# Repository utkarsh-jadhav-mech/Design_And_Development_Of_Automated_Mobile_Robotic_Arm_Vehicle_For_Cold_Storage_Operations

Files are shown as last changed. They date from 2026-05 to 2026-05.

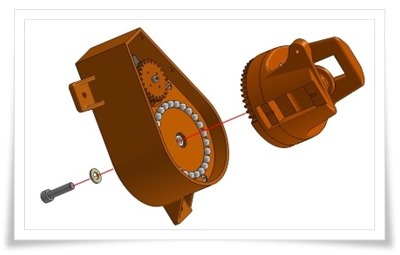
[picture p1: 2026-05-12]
Image/Assembly_Steps/Arm_Assembly_Steps/Software_Assembly/IMG-20241116-WA0014.jpg

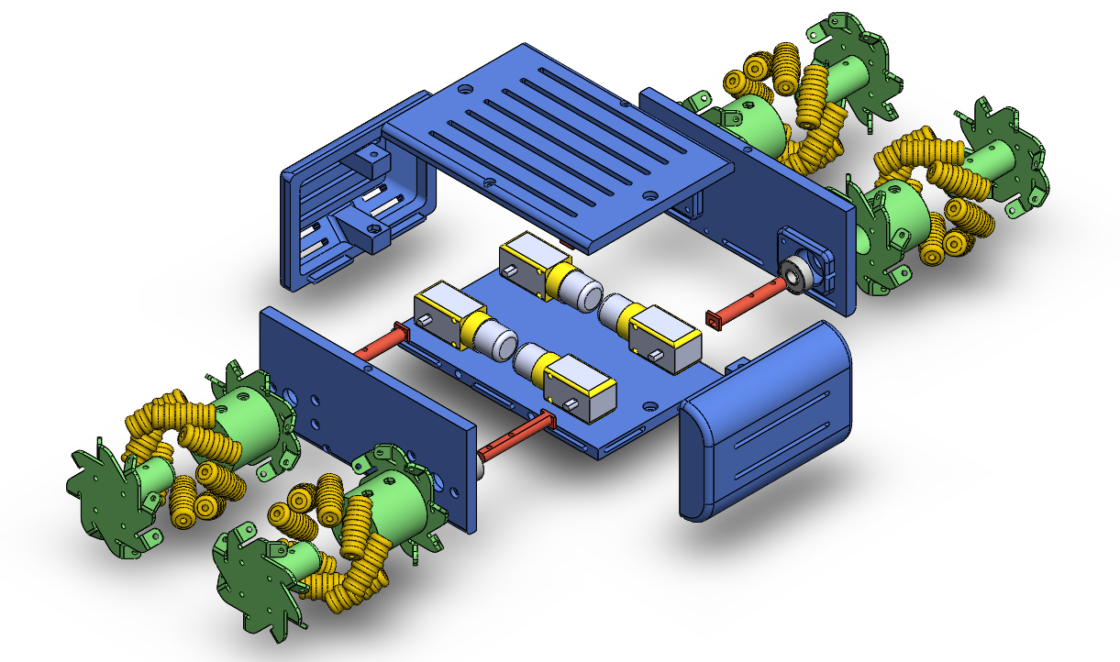
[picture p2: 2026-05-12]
Image/Assembly_Steps/Vehicle_Assembly_Steps/Software_Assembly/Exp_BLT_Pers.png

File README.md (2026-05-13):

# Design And Development of Automated Mobile Robotic Arm Vehicle for Cold Storage Operations

## Final Year Mechanical Engineering Project

An automated mobile robotic arm designed for cold storage operations to reduce manual labor, improve safety, and increase operational efficiency in low-temperature environments.

<br>
Final_Demontration
<br>

## Table of Contents

1. [Project Summary](#project-summary)  
2. [Project Overview](#project-overview)  
3. [Project Focus](#project-focus)  
4. [Project Objectives](#project-objectives)  
5. [Certificate of Journal and Conference](#certificate-of-journal-and-conference)
6. [Certificate Images](#certificate-images)
7. [Hardware Components](#hardware-components)
8.  [Software Used](#software-used)  
9. [Materials Used](#materials-used)  
10. [Engineering Calculations](#engineering-calculations)
11. [CAD Design](#cad-design)
12. [Working Principle](#working-principle)
13. [Project Development Process](#project-development-process)
14. [Results](#results)
15. [Applications](#applications)
16. [Skills Developed](#skills-developed)
17. [Contributing](#contributing)
18. [Future Improvements](#future-improvements)
19. [Author](#author)
20. [Final Note](#final-note)

## Project Summary

The **Automated Mobile Robotic Arm Vehicle for Cold Storage Operations** is a final year mechanical engineering project focused on automating material handling tasks in cold storage environments. The system combines a mobile robotic platform with a robotic arm capable of pick-and-place operations using Arduino-based control and Bluetooth communication.

The project utilizes components such as MG995 servo motors, Arduino Uno, HC-05 Bluetooth module, L298N motor driver, and 3D printed mechanical parts designed in SolidWorks. The robotic system is developed to reduce manual labor, improve operational safety, and increase efficiency in low-temperature industrial environments.

This project integrates mechanical design, embedded systems, robotics, CAD modeling, and automation technologies into a practical industrial application.

## Project Overview

The **Automated Mobile Robotic Arm Vehicle for Cold Storage Operations** is a final year mechanical engineering project designed to automate material handling tasks in cold storage environments. The system combines a mobile robotic platform with a robotic arm capable of performing pick-and-place operations through wireless Bluetooth control.

The project uses components such as Arduino Uno, MG995 servo motors, HC-05 Bluetooth module, L298N motor driver, and 3D printed mechanical parts. The main objective is to reduce manual labor, improve worker safety, and increase operational efficiency in low-temperature storage facilities through robotic automation.

## Project Focus

The main focus of this project is:
- Automation in cold storage environments
- Mobile robotics
- Robotic arm manipulation
- Wireless robotic control
- Embedded systems integration
- Mechanical system design

# Project Objectives

- Reduce manual labor in cold storage
- Improve operational safety
- Develop an automated handling system
- Enable wireless robotic control
- Design a low-cost automation solution
- Improve material transportation efficiency

## Certificate of Journal and Conference

### Journal Publication Certificate

This project research work was successfully published/presented in a reputed engineering journal based on robotics, automation, and cold storage applications.

#### Research Area
- Robotics and Automation
- Cold Storage Automation
- Embedded Systems
- Mobile Robotic Arm
- Industrial Automation

#### Published Research Title
**Development of Automated Mobile Robotic Arm Vehicle for Cold Storage Operations**

#### Journal Details
| Details | Information |
|---|---|
| Journal Name | IRJMETS |
| Paper ID |IRJMETS70400360229 |
| Volume | 07 |
| Issue | 04 |
| Publication Year | 2026 |
| ISSN Number | 2582-5208 |
| DOI | https://www.doi.org/10.56726/IRJMETS75091 |

### Conference Presentation Certificate

The project was also presented at a technical conference/seminar related to engineering innovation and automation technologies.

#### Conference Presentation Title
**Development of Automated Mobile Robotic Arm Vehicle for Cold Storage Operations**

#### Conference Details

| Details | Information |
|---|---|
| Conference Name | International Conference on Recent Advances in Engineering and Sciences – 2025 (ICRAES-2K25) |
| Organized By | Bharati Vidyapeeth’s College of Engineering, Lavale, Pune |
| Presentation Type | Technical Paper Presentation |
| Conference Year | 2025 |
| Location | Pune, India |

## Certificate Images

### Journal Certificate
<BR>
Journal_Certificate
<BR>

### Conference Certificate
<BR>
Conference_Certificate
<BR>

## Hardware Components

| Sr No | Component | Specification |
|---|---|---|
| 1 | Servo Motor | MG995 High Torque Servo |
| 2 | Micro Servo | SG90 |
| 3 | Controller | Arduino Uno |
| 4 | Servo Controller | USB Bluetooth 18 Servo Controller |
| 5 | Motor Driver | L298N |
| 6 | Bluetooth Module | HC-05 |
| 7 | Battery | Samsung 7.4V 2600mAh Li-Ion |
| 8 | Stepper Motor | NEMA Stepper Motor |
| 9 | Bearings | 606ZZ / 608ZZ |
| 10 | Wheels | Robotic Wheels |

## Software Used

- Arduino IDE
- SolidWorks
- Tinkercad
- RoboKits Servo Controller Software
- FlashPrint

## Materials Used

| Material | Purpose |
|---|---|
| PLA Filament | 3D Printed Parts |
| Aluminum Frame | Structural Support |
| Rubber Wheels | Mobile Movement |
| Bearings 606ZZ / 608ZZ | Smooth Rotation |
| Servo Mounts | Joint Assembly |

## Engineering Calculations

### Payload Capacity

- Expected Payload = 100 g
- Safety Factor = 1.5
- Safe Payload = 150 g

### Torque Calculation

Formula:

```math
T = F × r
```

Calculated Torque:
- Force = 1.962 N
- Torque = 0.981 N·m
- Equivalent Torque ≈ 10 kg/cm

### Power Consumption

```math
P = V × I
```

- Voltage = 6V
- Current = 2.5A
- Total Power = 45W

### Battery Backup

- Battery Energy = 19.24 Wh
- Estimated Backup = 26 Minutes

## CAD Design

The robotic arm and chassis were designed using **SolidWorks**.

Designed Components:
- Robotic arm links
- Gripper mechanism
- Servo mounts
- Mobile chassis
- Wheel assembly

The CAD models were exported as STL files for 3D printing.

## Working Principle

1. User sends command via Bluetooth.
2. HC-05 module receives data.
3. Arduino processes the command.
4. Servo controller drives robotic arm motors.
5. L298N controls wheel movement.
6. Robotic arm performs handling operation.

## Project Development Process

### Step 1 — Requirement Analysis
- Studied cold storage operational problems
- Identified automation requirements

### Step 2 — CAD Modeling
- Designed robotic arm in SolidWorks
- Created assembly and motion design

### Step 3 — 3D Printing
- Converted STL files
- Printed mechanical components

### Step 4 — Electronics Integration
- Connected Arduino and motor drivers
- Installed Bluetooth communication system

### Step 5 — Programming
- Developed Arduino control code
- Implemented motor movement logic

### Step 6 — Testing
- Tested robotic arm movement
- Checked wireless communication
- Performed cold condition trials

## Results

- Successful robotic movement
- Stable Bluetooth communication
- Reliable pick-and-place operation
- Accurate servo control
- Efficient mobility in testing conditions

## Applications

- Cold storage warehouses
- Industrial automation systems
- Smart logistics and material handling
- Food and pharmaceutical storage facilities
- Hazardous environment operations

## Skills Developed

- SolidWorks CAD Modeling
- 3D Printing
- Basic Arduino Programming
- Embedded Systems
- Robotics Integration
- Mechanical Assembly
- Engineering Design

## Contributing

Contributions, suggestions, and improvements related to CAD modeling, simulation, robotic arm control, and automated mobile robotic system design for cold storage applications are welcome. Feel free to fork the repository and submit pull requests for enhancements.

## Future Improvements

- AI-based navigation
- Computer vision integration
- IoT monitoring system
- Implementation of autonomous navigation using SLAM
- AI-based object detection for intelligent picking
- IoT-based monitoring system
- Fully automated charging station integration
- Multi-robot coordination for warehouse automation
- Obstacle avoidance system

## Author

**Utkarsh Jadhav**  
Mechanical Engineering Student | CAD Designer | Robotics Enthusiast  

- GitHub: https://github.com/utkarsh-jadhav-mech
- LinkedIn: https://www.linkedin.com/in/utkarsh-jadhav-mech

### Team Members
- Girish Patil
- Subodh Bhosale
- Sunil Dhargude
- Omkar Pore

### Guided By
**Prof. S. H. Kumbhar** 

## Final Note

This project represents an integration of mechanical design, electronics, and automation for cold storage applications. It demonstrates the practical implementation of a mobile robotic arm system aimed at improving efficiency, safety, and productivity in industrial environments.

Continuous improvements and innovative ideas are always encouraged to enhance the performance and real-world applicability of this system.

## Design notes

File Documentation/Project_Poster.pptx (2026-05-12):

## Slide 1

“Development of Automated Mobile Robotic Arm for Cold Storage Operations”

Subodh Bhosale (244418 ) Girish Patil (244425) Utkarsh Jadhav (244426)
Omkar Pore (244460) Sunil Dhargude (244464 )
Under Guidance of :- Prof. S. H. Kumbhar
Academic Year 2024-25
Department of Mechanical Engineering, VPKBIET Baramati

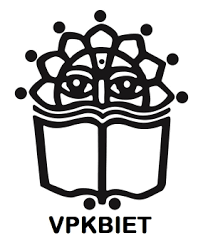
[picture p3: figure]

Abstract

The development of an automatic mobile robotic arm for cold storage operations is aimed at enhancing efficiency, accuracy and security in the environment, where temperature-sensitive items are handled. This robotic system is designed to autonomally navigate cold storage features, pick, sort and store items and operate tasks such as storing and operating in tight temperature conditions. This innovation is particularly important for industries such as food and pharmaceuticals, where it is important to maintain the integrity of temperature
sensitive products. Robotic arm dynamics allow it to make it favourable to various cold storage configurations, while its exact control mechanisms ensure safe handling of delicate objects. The system not only strengthens operations, but also improves security by reducing human risk for extremely cold environment, which leads to better overall productivity and cost savings.

Objectives

- Robotic Arm Design & Development
- Cold-Resistant Materials & Components
- Enhanced Speed & Precision
- Worker Safety & Injury Prevention
- System Testing & Optimization
- AI & Automation Integration

Results

For the development of an automated mobile robotic arm in cold storage operations:
• The payload capacity should be designed for at least 0.26 kg with an overload protection factor.
• The joint torque requirement is 10.00 kg.cm (98.1 N.cm) for smooth operation.
• The motor power requirement is 2.05 W, ensuring energy-efficient operation.
These calculations provide a fundamental basis for selecting appropriate actuators, ensuring reliability in cold storage environments. Further refinements should consider frictional losses, joint dynamics, and environmental
adaptations.

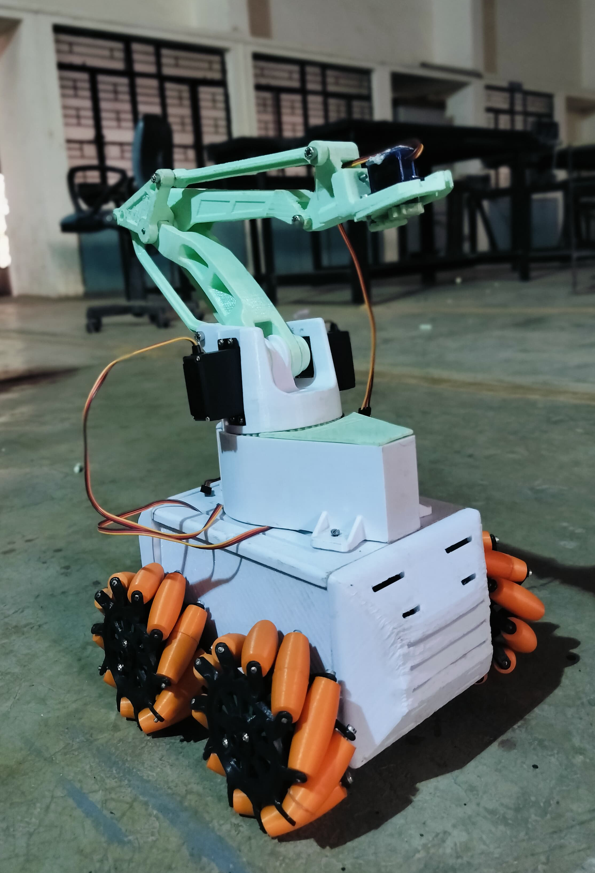
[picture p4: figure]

Methodology

- Design of Robotic Arm
- Motor and Servo Selection for Cold Storage
- Battery and Power Management System
- Mobility and Navigation System
- Control System and Software Integration
- Testing and Evaluation Protocol

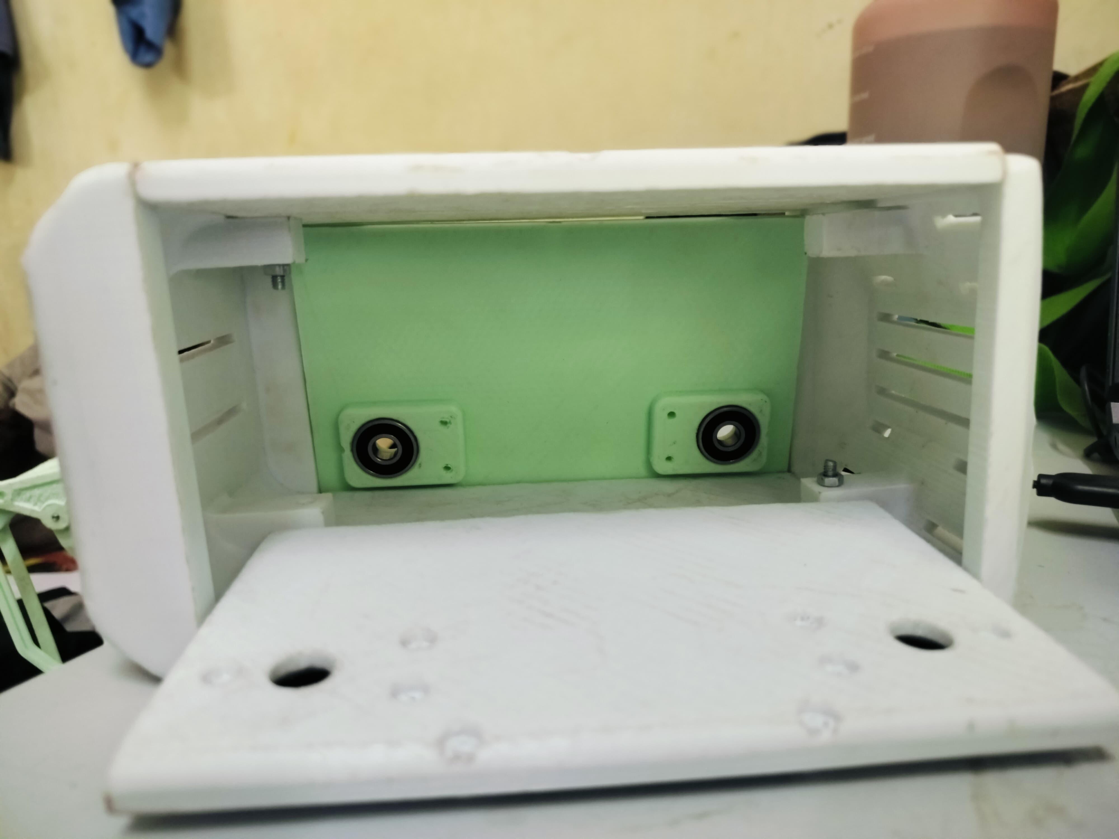
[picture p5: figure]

Fig.1 Automated Robotic Car Assembly Part

Fig.2 Robotic Aram Assembly Part

Introduction

Cold storage facilities play a crucial role in industries like food processing, pharmaceuticals, and biotechnology, where temperature-sensitive goods need to be stored and transported under controlled conditions. However, the extreme low temperatures in these environments create significant challenges for traditional manual handling and existing automation systems. Workers face health risks, and productivity is often slow and labor-intensive.
To address these challenges, automation in cold storage is increasingly becoming a necessity. Automated systems, such as robotic arms and mobile platforms, can enhance efficiency, reduce human exposure to cold, and improve safety. However,
most existing systems are not designed for the harsh conditions of cold storage, limiting their effectiveness.
This project focuses on the development of an “Automated Mobile Robotic Arm (AMRA)” for cold storage environments. The goal is to design a robotic arm capable of autonomously retrieving, placing, and transporting items with high precision in sub-zero temperatures. The robotic arm will be mounted on a mobile platform, allowing it to navigate aisles, avoid obstacles, and adapt to different layouts within the cold storage facility.
The aim is to improve operational efficiency, reduce labor costs, and enhance worker safety by minimizing human intervention. This system will also ensure the
careful handling of temperature-sensitive goods, thus improving the overall productivity and safety of cold storage operations. The following sections will detail
the design, development, and testing of the AMRA, focusing on its hardware, software, and integration into a cold storage environment..

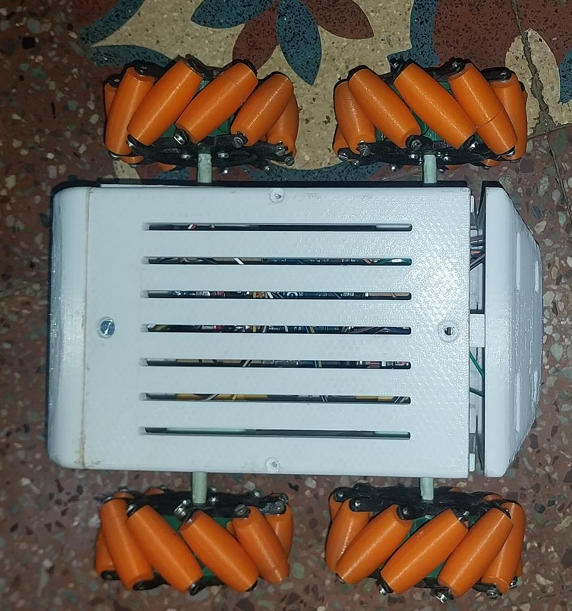
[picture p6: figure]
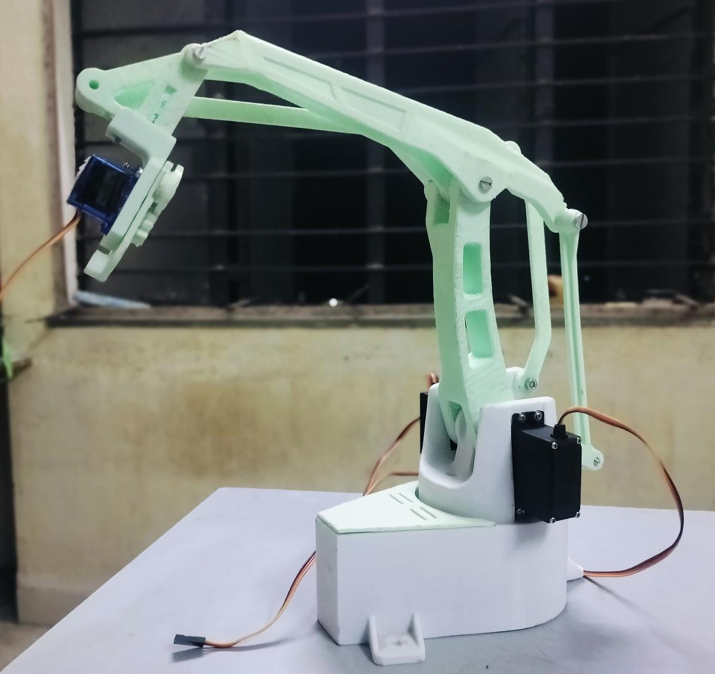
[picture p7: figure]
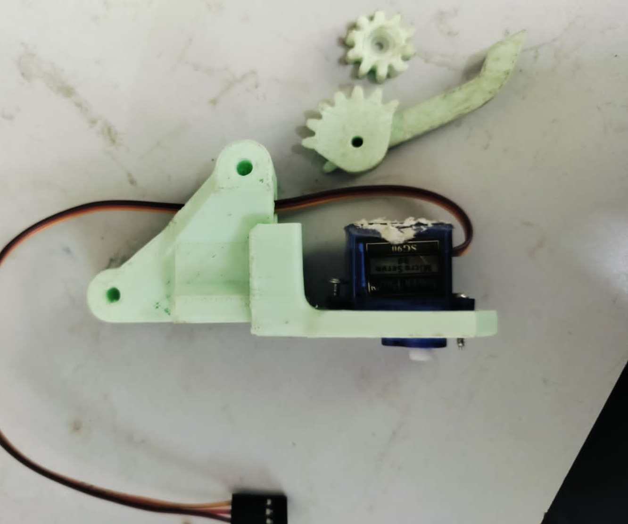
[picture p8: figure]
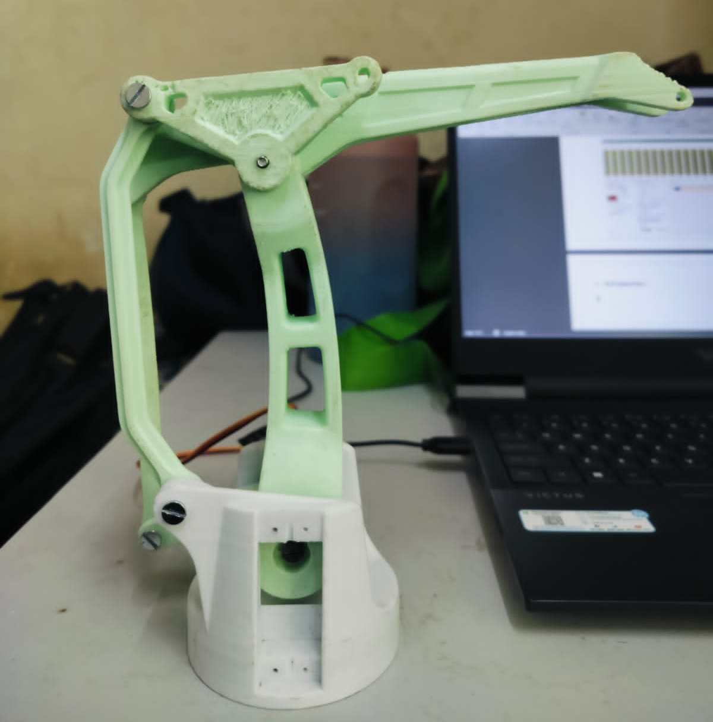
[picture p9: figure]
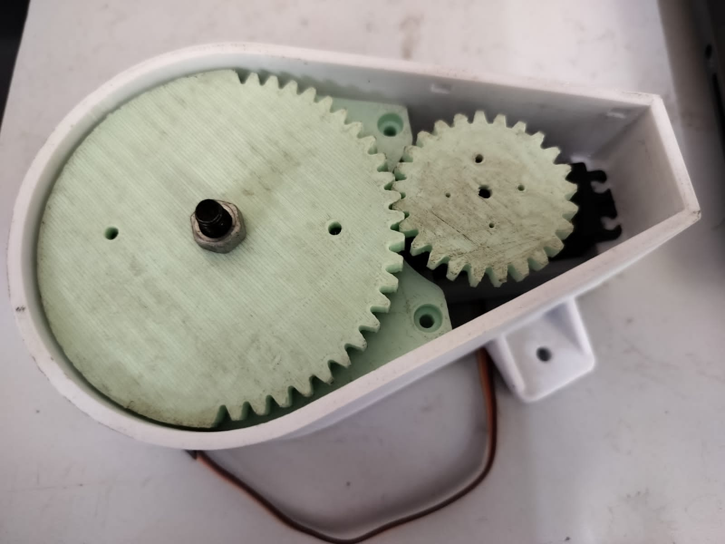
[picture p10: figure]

Conclusion

Integrating the EEZYBotArm MK2 with an omnidirectional mobile platform enhances efficiency in industrial settings like cold storage. This setup enables precise manipulation, flexible mobility, and seamless navigation. Future advancements may include AI automation, advanced sensors, and IoT connectivity for real-time optimization, boosting productivity and safety.

References

1.Smith, J. A., & Doe, R. (2022). Robotic Arms in Industrial Automation. Journal of Robotics, 15(4), 123-134.
2. Lee, C., & Wang, H. (2021). Advancements in Cold Storage Automation. International Conference on Robotics and Automation, 98-106.
3. Brown, T., & Green, R. (2020). Impact of Low Temperatures on Robotic Systems. Journal of Mechanical Design, 142(6), 654-670.
4. CESAREO CONTRERAS Autonomous Mobile Robot Makers Answer the Call During Holiday Rush.
5. Namita Sharma, Sadaf Anjum, Amrah Maryam, Savita Gautam (2024), Robotic Arm Car: A Mobile Solution For Automated Pick And Place Operations.

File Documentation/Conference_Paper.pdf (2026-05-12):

# Design and development of automated mobile robotic arm vehicle for cold storage operations

1

st Mr. Omkar Pore
dept.of Mechanical engineering VPKBIET, Baramati
Baramati,India
omkarpore03@gmail.com

4

th Mr. Subodh Bhosale
dept.of Mechanical Engineering VPKBIET, Baramati
Baramati, India
subodhbhosale0803@gmail.com

2

nd Mr. Girish Patil
dept.of Mechanical Engineering VPKBIET, Baramati
Baramati, India
girishpatil1705@gmail.com

5

th prof. Suraj Kumbhar
dept.of Mechanical Engineering VPKBIET, Baramati
Baramati, India
surajkumbhar6@gmail.com

3

rd Mr. Utkarsh Jadhav
dept.of Mechanical Engineering VPKBIET,Baramati
Baramati, India
utkarshjadhav994@gmail.com

Abstract— The development of an automatic mobile robotic arm for cold storage operations is aimed at enhancing efficiency, accuracy and security in the environment, where temperature-sensitive items are handled. This robotic system is designed to autonomally navigate cold storage features, pick, sort and store items and operate tasks such as storing and operating in tight temperature conditions. This innovation is particularly important for industries such as food and pharmaceuticals, where it is important to maintain the integrity of temperature-sensitive products. Robotic arm dynamics allow it to make it favourable to various cold storage configurations, while its exact control mechanisms ensure safe handling of delicate objects. The system not only strengthens operations, but also improves security by reducing human risk for extremely cold environment, which leads to better overall productivity and cost savings.

Keywords— Automatic mobile robotic arm, robotic system

I. INTRODUCTION
Cold storage warehouses play a crucial role in supply chains for perishable goods such as food, pharmaceuticals, and chemicals. However, extreme cold temperatures (as low as -30°C) make human labor inefficient, causing fatigue, reduced productivity, and health risks. Traditional robotic solutions are often fixed in place, limiting adaptability in dynamic storage environments.This research aims to develop a mobile robotic arm system capable of navigating cold storage environments, identifying goods, and performing automated retrieval and placement operations. The system is designed to work autonomously or via remote control, using AI-based object
recognition, | LiDAR-based | navigation, | and | real-time
environmental adaptation.

II. LITERATURE SURVEY

A. litarature review
- Cold Storage Challenges in Warehouse Automation. Cold storage environments present unique challenges for automation, primarily due to extreme temperatures affecting mechanical components, electronics, and human labor. Studies by Bakker et al. (2021) highlight that worker fatigue and health risks significantly impact operational efficiency in sub-zero environments. Traditional robotic systems struggle with condensation, low battery performance, and material brittleness at extremely low temperatures (Kim & Lee, 2020).
- Robotic Systems for Warehouse Automation
The application of robotics in warehouses has been widely explored, particularly through Automated Storage and

Retrieval Systems (AS/RS). Research by Zhong et al. (2019) emphasizes that AS/RS improves efficiency and reduces labor costs, but these systems are typically fixed, limiting adaptability in dynamic environments. Autonomous Mobile Robots (AMRs), such as those developed by Amazon Robotics and Fetch Robotics, have shown promise in general warehouse automation, but studies indicate they require modifications for cold storage, including insulation and specialized sensors (Gao et al., 2022).
- Mobile Robotic Arms in Logistics
Mobile robotic arms combine the benefits of mobility and precise object manipulation. Wurman et al. (2017) explored the use of robotic arms for logistics applications, noting improvements in order fulfillment speed. However, their effectiveness in cold storage has not been extensively studied. More recent advancements, such as those by Gupta et al. (2023), demonstrate AI-powered mobile robots performing autonomous retrieval and placement, but without adaptations for sub-zero conditions.
- | AI-Based | Object | Recognition | for | Cold
Environments

AI-based vision systems have been widely adopted in warehouse automation, with Convolutional Neural Networks (CNNs) and deep learning models proving effective in object detection and classification (Redmon & Farhadi, 2018). However, cold storage conditions introduce challenges such as frost accumulation, low lighting, and visual obstructions due to fogging (Chen et al., 2021). Solutions such as infrared imaging and sensor fusion have been proposed to enhance object recognition reliability in extreme conditions (Huang et al., 2022).

- LiDAR-Based Navigation in Cold Storage

LiDAR-based navigation enables precise mapping and localization in warehouse environments. Research by Thrun et al. (2020) demonstrates that LiDAR combined with SLAM
(Simultaneous | Localization | and | Mapping) | enhances
autonomous robot navigation. However, cold storage warehouses with narrow aisles and reflective surfaces introduce mapping inaccuracies (Park et al., 2023). Newer approaches, such as multi-sensor fusion combining LiDAR with thermal and ultrasonic sensors, have been suggested to
improve | navigation | robustness | in | low-temperature
environments.
- Real-Time Environmental Adaptation in Robotics

Real-time environmental adaptation is crucial for autonomous operations in dynamic storage environments. Khatib (2022) explored adaptive control algorithms for robotic manipulators, emphasizing their role in adjusting to temperature-induced mechanical variations. Machine learning-driven adaptation strategies have been proposed by Liu et al. (2023), where reinforcement learning enables robots to modify movement patterns based on environmental feedback, reducing operational failures in extreme conditions. The development of an Automated Mobile Robotic Arm for Cold Storage Operations follows a structured and systematic approach to ensure efficient material handling, precise object recognition, and real-time adaptation to harsh environmental conditions. The process involves a series of research, design, prototyping, testing, and optimization phases to create a reliable and costeffective robotic solution tailored for cold storage warehouse automation.

III. PROBLEM IDENTIFICATION
Cold storage warehouses require efficient automation due to extreme environmental conditions that affect both human labour and traditional robotic systems. While mobile robotic arms offer flexibility in material handling, their deployment in sub-zero environments presents several critical challenges
A. Environmental Challenges in Cold Storage
Extreme Temperatures: Mechanical components become brittle, lubricants lose efficiency, and batteries Experience reduced performance in freezing conditions. Condensation & Frost Formation: Rapid temperature fluctuations lead to moisture build up, affecting sensors, Electronics, and vision systems. Low Visibility & Lighting Issues: Cold storage warehouses often have dim lighting, And fogging further obstructs cameras and LiDAR sensors.
B. Limitations of Current Robotics in Cold Storage
- Fixed AS/RS Systems: Traditional Automated Storage and Retrieval Systems (AS/RS) lack adaptability in dynamic warehouse settings.
- AMR Challenges: Autonomous Mobile Robots (AMRs) used in standard warehouses require modifications, such as insulation and specialized
sensors, | to | function | effectively | in | cold
environments.Lack | of | Mobile | Manipulation:
Existing robotic arms used in logistics are often stationary and not optimized for mobility in cold storage.
C. Key Development Phases:
- Research & Requirements Analysis:
Identify | challenges | related | to | low | temperatures,
condensation, and limited human intervention in cold storage environments. Study AI-based object recognition, LiDAR-based navigation, and reinforcement learning for real-time adaptation. Analyze material compatibility for cold-resistant components, sensors, and actuators to ensure longevity.
- Design & System Architecture:
Develop a mobile robotic platform with an integrated robotic arm capable of operating in sub-zero conditions. Design an AI-driven vision system for recognizing, localizing, and manipulating objects accurately. Incorporate insulation and heating elements to prevent sensor and mechanical failures due to extreme cold.
- Prototyping & Hardware Integration:
Build | a | functional | prototype | with | industrial-grade
components suited for cold environments. Integrate LiDAR, depth cameras, and AI-based vision for precise navigation and object interaction. Develop a real-time control system with reinforcement learning-based adaptation for dynamic warehouse conditions.
Testing & Performance Evaluation:
Conduct extensive cold storage trials to assess system robustness, energy efficiency, and automation reliability. Optimize gripping mechanisms to ensure stable handling of frozen goods and temperature-sensitive items. Evaluate battery performance and power management under extreme cold conditions.
- Optimization & Deployment:
Enhance AI models for improved object detection and navigation accuracy. Refine motion planning algorithms for real-time adjustments to dynamic warehouse layouts. Implement seamless integration with existing warehouse management systems (WMS) for autonomous operation.

IV. MODELING AND WORKING
A. Design Explanation:

1.Structural Design

Material: The arm is made from 3D-printed plastic (likely PLA or ABS), making it lightweight yet sturdy.

Segmented Arm: The design includes multiple articulated sections, mimicking industrial robotic arms.

2. Actuation & Motion

Servo Motors: Several hobby-grade servo motors (visible in black casings) control the different joints, enabling movement in multiple degrees of freedom. Gear System: The base houses a visible orange gear mechanism that helps in rotating the arm.

3. Mechanical Linkages

Parallel Linkage Mechanism: The arm utilizes parallel linkages to ensure smooth and controlled movement of the end effector. Bolted Joints: Screws and metal bolts reinforce key pivot points for added durability.

4.End Effector (Gripper)

Servo-Powered Claw: The gripper is controlled by a small servo motor, enabling it to grasp objects.

5.Base and Mounting

Sturdy Base: The base is designed to be mounted or placed on a flat surface for stability.

Mounting Holes: Visible at the bottom for securing the arm to a surface.

B. Conceptual Design & Prototyping
The conceptual design and layout is developed using SolidWorks. This phase involved creating a comprehensive 3D model that integrated key components such as sensors, extinguishing mechanisms, and housing structures. By leveraging SolidWorks, we refined the spatial arrangement of each component to achieve a compact and Efficient layout that aligns with the structural framework of an electric vehicle. This design process facilitated a Thorough analysis of spatial constraints, ultimately enhancing both the functionality and safety of the fire Suppression system. After immense prototyping & improvements the finalization of design is done & the design Includes all the major key components of the system.

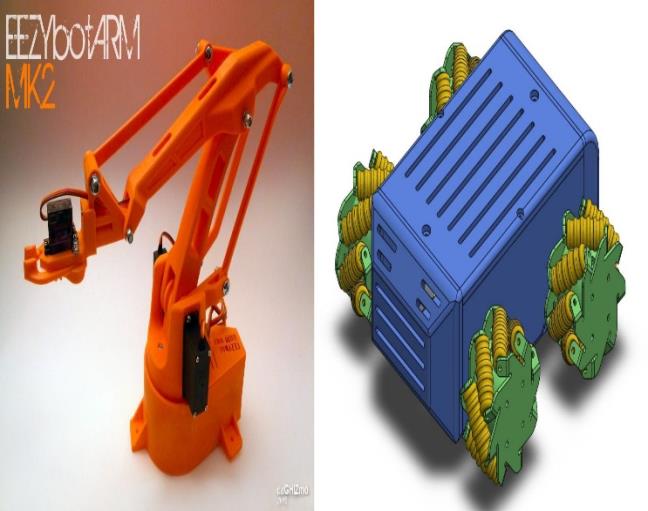
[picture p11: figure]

Fig. Conceptual design of robot.

C. Layout & Its Key Features

Layout

The following design is made, and the image gives an idea about the layout of all the components.

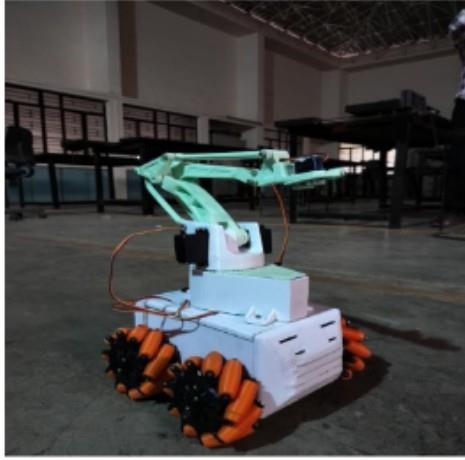
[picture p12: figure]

Fig. Assembly of robotic system

Key features
1. Integrated Mobile Base & Robotic Arm – Combines an articulated robotic arm with an omnidirectional mobile Platform.
2. Omnidirectional Mecanum Wheels – Enables smooth and precise movement in any direction for efficient Warehouse navigation.
3. Compact & Modular Design – Ensures easy integration into automated logistics and warehouse operations.
4. Servo-Driven Arm with Multi-DOF – Provides precise object manipulation and picking capabilities.
5. AI-Driven Navigation & Object Recognition – Uses LiDAR and vision sensors for real-time mapping and object Detection.
6. Cold-Resistant Construction – Designed to operate in low-temperature environments with protected Electronics.
7. Versatile End-Effector – Capable of handling various object types with adaptive gripping mechanisms.
8. Autonomous Operation – Can be programmed for self-guided tasks, reducing manual intervention.
Working
The mobile robotic arm operates seamlessly with a mobile controller system, enabling remote and autonomous Control for warehouse automation. The controller interfaces via Wi-Fi, Bluetooth, or a dedicated RF module, Allowing real-time communication between the user and the robot. Using a custom mobile app or joystick-based Interface, operators can manually control movement, adjust arm positioning, and activate object-gripping Functions. The system also supports autonomous mode, where AI-driven navigation and object recognition guide Operations based on preprogrammed tasks. Equipped with LiDAR and sensor fusion, the robotic arm adapts to Obstacles dynamically. The mobile controller enhances usability, flexibility, and efficiency, making the system ideal for cold storage and logistics automation

Pick and Place Process:
1. The pick and place operation of the mobile robotic arm follows a structured sequence, integrating AI-driven Perception, precise actuation, and autonomous navigation for efficient object handling.
2. Object Detection & Localization – Using AI-based vision and LiDAR sensors, the system identifies and locates Objects within its workspace.
3. Navigation & Positioning – The Mecanum wheel base moves the robot to the optimal position, ensuring precise Alignment with the target object.3. Arm Actuation & Gripping – The multi-DOF robotic arm extends toward the Object, and the adaptive gripper (vacuum, soft, or electromagnetic) securely grasps it.
4. Transport & Repositioning – The robotic system moves to the designated drop-off location, optimizing its path Through autonomous route planning.
5. Object Placement & Release – The arm accurately positions and releases the object at the specified location Before returning to its idle state or next task.

Analysis & Calculations :

1. Payload Capacity and Overload protection :
This is the maximum weight that robotic arm is designed to lift (assumption) and safety margin has to 1.3 more than load.

P safe = P exact load × safety factor.

P safe = 200 mg ×1.3 = 130 mg = 260 mg

2. Torque Calculation for Arm Joints :
T = F × r | (F= m ×g =0.200×9.81= 1.962 N)
T = 1.962 × 50 = 98.1N.cm | (r=50 cm overall height)

T = 10.00 kg. cm

3. Motor Power :

P = T × w / 1000

P = 0.981 × (2π/t) / 1000 | ( t= 3 sec)

P = 0.00205 Kw | (P = 2.05W)

Result :

For the development of an automated mobile robotic arm in cold storage operations:
- The payload capacity should be designed for at least 0.26 kg with an overload protection factor.
- The joint torque requirement is 10.00 kg.cm (98.1 N.cm) for smooth operation.
- The motor power requirement is 2.05 W, ensuring energy-efficient operation.
These calculations provide a fundamental basis for selecting appropriate actuators, ensuring reliability in cold storage environments. Further refinements should consider frictional losses, joint dynamics, and environmental adaptations.

Conclusion :

The integration of an automated mobile robotic arm, such as the EezyBotArm MK2, with an omnidirectional mobile platform presents a promising solution for enhancing efficiency in industrial and specialized environments like cold storage warehouses. This combination enables precise object manipulation and flexible mobility, allowing seamless navigation in constrained spaces. The robotic system’s modularity and adaptability make it suitable for various applications, from logistics to precision assembly. Future improvements could focus on AI-driven automation, advanced sensor integration, and IoT connectivity for real-time monitoring and optimization. This development contributes to the ongoing advancement of smart robotics, improving productivity and operational safety.

References :

[1]. Bakker, T., Jansen, P., & De Vries, M. (2021). Human fatigue and productivity decline in sub-zero warehouse Environments. International Journal of Logistics Research and Applications, 24(3), 205-219.

[2]. Kim, H., & Lee, S. (2020). Material degradation and sensor performance in cold storage robotics. Journal of Robotics and Automation, 35(4), 355-372.

[3]. Zhong, R. Y., Xu, G., Klotz, E., & Newman, S. T. (2019). Intelligent manufacturing in the context of industry 4.0: A Review. Engineering, 5(4), 616-630.

[4]. Gao, X., Liu, Y., & Wang, H. (2022). Autonomous mobile robots in logistics: Applications and challenges. IEEE Transactions on Industrial Informatics, 18(2), 905-918.

[5]. Wurman, P. R., D’Andrea, R., & Mountz, M. (2017). Coordinating hundreds of autonomous robots for warehouse Automation. AI Magazine, 29(2), 9-20.

[6]. Gupta, A., Mehta, P., & Sharma, R. (2023). AI-powered robotic arms for warehouse automation: Advances and limitations. Journal of Artificial Intelligence and Robotics, 12(1), 45-62.

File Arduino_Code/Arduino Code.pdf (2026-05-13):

# Arduino Code

#include <SoftwareSerial.h>

#include <Servo.h>

Servo servo01;

Servo servo02;

Servo servo03;

Servo servo06;

#define relay1 6

#define relay2 7

#define relay3 8

#define relay4 9

SoftwareSerial Bluetooth(0, 1); // Arduino(RX, TX) - HC-05 Bluetooth (TX, RX)

int wheelSpeed = 1500;

int lbw[50], lfw[50], rbw[50], rfw[50]; // arrays for storing positions/steps

int servo1Pos, servo2Pos, servo3Pos, servo4Pos, servo5Pos, servo6Pos; // current position

int servo1PPos, servo2PPos, servo3PPos, servo4PPos, servo5PPos, servo6PPos; // previous position

int servo01SP[50], servo02SP[50], servo03SP[50], servo04SP[50], servo05SP[50], servo06SP[50]; // for storing positions/steps

int speedDelay = 20;

int index = 0;

int dataIn;

int m = 0;

void setup() {

pinMode(relay1, OUTPUT);

pinMode(relay2, OUTPUT);

pinMode(relay3, OUTPUT);

pinMode(relay4, OUTPUT);

digitalWrite(relay1, LOW);

digitalWrite(relay2, LOW);

digitalWrite(relay3, LOW);

digitalWrite(relay4, LOW);

// Set initial seed values for the steppers

servo01.attach(2);

servo02.attach(3);

servo03.attach(4);

servo06.attach(5);

Bluetooth.begin(9600); // Default baud rate of the Bluetooth module

Bluetooth.setTimeout(5);

delay(20);

Serial.begin(38400);

// Move robot arm to initial position

servo1PPos = 90;

servo01.write(servo1PPos);

servo2PPos = 100;

servo02.write(servo2PPos);

servo3PPos = 120;

servo03.write(servo3PPos);

servo6PPos = 110;

servo06.write(servo6PPos);

}

void loop() {

// Check for incoming data

if (Bluetooth.available() > 0) {

dataIn = Bluetooth.read(); // Read the data

Serial.println(dataIn);

if (dataIn == 0) {

m = 0;

}

if (dataIn == 1) {

m = 1;

}

if (dataIn == 2) {

m = 2;

}

if (dataIn == 3) {

m = 3;

}

if (dataIn == 4) {

m = 4;

}

if (dataIn == 5) {

m = 5;

}

if (dataIn == 6) {

m = 6;

}

if (dataIn == 7) {

m = 7;

}

if (dataIn == 8) {

m = 8;

}

if (dataIn == 9) {

m = 9;

}

if (dataIn == 10) {

m = 10;

}

if (dataIn == 11) {

m = 11;

}

if (dataIn == 12) {

m = 12;

}

if (dataIn == 14) {

m = 14;

}

if (dataIn == 16) {

m = 16;

}

if (dataIn == 17) {

m = 17;

}

if (dataIn == 18) {

m = 18;

}

if (dataIn == 19) {

m = 19;

}

if (dataIn == 20) {

m = 20;

}

if (dataIn == 21) {

m = 21;

}

if (dataIn == 22) {

m = 22;

}

if (dataIn == 23) {

m = 23;

}

if (dataIn == 24) {

m = 24;

}

if (dataIn == 25) {

m = 25;

}

if (dataIn == 26) {

m = 26;

}

if (dataIn == 27) {

m = 27;

}

// Move the Mecanum wheels platform

if (m == 2) {

moveForward();

}

if (m == 7) {

moveBackward();

}

if (m == 9) {

rotateLeft();

}

if (m == 10) {

rotateRight();

}

if (m == 0) {

stopMoving();

}

// Mecanum wheels speed

if (dataIn > 30 & dataIn < 100) {

wheelSpeed = dataIn * 20;

}

// Move robot arm

// Move servo 1 in positive direction

while (m == 16) {

if (Bluetooth.available() > 0) {

m = Bluetooth.read();

}

servo01.write(servo1PPos);

servo1PPos++;

delay(speedDelay);

}

// Move servo 1 in negative direction

while (m == 17) {

if (Bluetooth.available() > 0) {

m = Bluetooth.read();

}

servo01.write(servo1PPos);

servo1PPos--;

delay(speedDelay);

}

// Move servo 2

while (m == 19) {

if (Bluetooth.available() > 0) {

m = Bluetooth.read();

}

servo02.write(servo2PPos);

servo2PPos++;

delay(speedDelay);

}

while (m == 18) {

if (Bluetooth.available() > 0) {

m = Bluetooth.read();

}

servo02.write(servo2PPos);

servo2PPos--;

delay(speedDelay);

}

// Move servo 3

while (m == 20) {

if (Bluetooth.available() > 0) {

m = Bluetooth.read();

}

servo03.write(servo3PPos);

servo3PPos++;

delay(speedDelay);

}

while (m == 21) {

if (Bluetooth.available() > 0) {

m = Bluetooth.read();

}

servo03.write(servo3PPos);

servo3PPos--;

delay(speedDelay);

}

// Move servo 6

while (m == 26) {

if (Bluetooth.available() > 0) {

m = Bluetooth.read();

}

servo06.write(servo6PPos);

servo6PPos++;

delay(speedDelay);

}

while (m == 27) {

if (Bluetooth.available() > 0) {

m = Bluetooth.read();

}

servo06.write(servo6PPos);

servo6PPos--;

delay(speedDelay);

}

// If arm speed slider is changed

if (dataIn > 101 & dataIn < 250) {

speedDelay = dataIn / 10; // Change servo speed (delay time)

}

// If button "RUN" is pressed

if (m == 14) {

runSteps();

// If button "RESET" is pressed

if (dataIn != 14) {

stopMoving();

memset(lbw, 0, sizeof(lbw)); // Clear the array data to 0

memset(lfw, 0, sizeof(lfw));

memset(rbw, 0, sizeof(rbw));

memset(rfw, 0, sizeof(rfw));

memset(servo01SP, 0, sizeof(servo01SP)); // Clear the array data to 0

memset(servo02SP, 0, sizeof(servo02SP));

memset(servo03SP, 0, sizeof(servo03SP));

memset(servo06SP, 0, sizeof(servo06SP));

index = 0; // Index to 0

}

}

}

}

void moveForward() {

digitalWrite(relay1, HIGH);

digitalWrite(relay2, LOW);

digitalWrite(relay3, HIGH);

digitalWrite(relay4, LOW);

}

void moveBackward() {

digitalWrite(relay1, LOW);

digitalWrite(relay2, HIGH);

digitalWrite(relay3, LOW);

digitalWrite(relay4, HIGH);

}

void rotateLeft() {

digitalWrite(relay1, HIGH);

digitalWrite(relay2, LOW);

digitalWrite(relay3, LOW);

digitalWrite(relay4, HIGH);

}

void rotateRight() {

digitalWrite(relay1, LOW);

digitalWrite(relay2, HIGH);

digitalWrite(relay3, HIGH);

digitalWrite(relay4, LOW);

}

void stopMoving() {

digitalWrite(relay1, LOW);

digitalWrite(relay2, LOW);

digitalWrite(relay3, LOW);

digitalWrite(relay4, LOW);

}

// Automatic mode custom function - run the saved steps

void runSteps() {

}

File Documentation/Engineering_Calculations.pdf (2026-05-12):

## Engineering Calculations

### 1. Payload Capacity Calculation

The robotic arm is designed to safely lift lightweight objects in cold storage environments.

Formula:

Psafe = Pexpected × Safety Factor

- Expected Payload = 100 g
- Safety Factor = 1.5

Calculation:

Psafe= 100 × 1.5 = 150 g

Result:

Safe Payload Capacity = 150 g

### 2. Torque Calculation for Robotic Arm

Torque required for lifting operation.

Formula:

T = F × r

Where:

- Force:

F = m × g

Given:

- Mass = 0.2 kg
- Gravity = 9.81 m/s²
- Arm Length = 0.5 m

Force Calculation:

F = 0.2 × 9.81 = 1.962 N

Torque Calculation:

T = 1.962 × 0.5 = 0.981 N ⋅ m

Equivalent Servo Torque:

≈ 10 kg/cm

This validates the use of MG995 servo motors.

### 3. Power Consumption Calculation

Formula:

P = V × I

For one MG995 Servo Motor:

- Voltage = 6V
- Current = 2.5A

Power for one servo:

P = 6 × 2.5 = 15 W

For 3 Servo Motors:

Ptotal= 3 × 15 = 45 W

Result:

Total Servo Power Consumption = 45 W

### 4. Motor Power Calculation

Formula:

T × ω

Pmotor= | 1000

Given:

- Torque = 0.981 N·m
- Angular Velocity = 2.05 rad/s

Calculation:

0.
Pmotor == 2.05 W

Result:

Motor Power = 2.05 W

### 5. Battery Energy Calculation

Formula:

Energy = Battery Capacity × Voltage

Given:

- Battery Capacity = 2.6 Ah
- Voltage = 7.4 V

Calculation:

Energy = 2.6 × 7.4 = 19.24 Wℎ

Result:

Battery Energy = 19.24 Wh

### 6. Battery Backup Time Calculation

Formula:

Battery Energy
Battery Life =
Power Consumption

Calculation:

Battery Life = = 0.43 ℎours

Convert to minutes:

0.43 × 60 = 26 minutes

Result:

Estimated Battery Backup = 26 Minutes

### 7. Stress Analysis

Used for validating robotic arm structural safety.

Formula:

F
σ =
A
Given:
- Load Force:

F = 1.962 N

Assume:

- Cross-sectional Area of arm = 200 mm²

Convert area:

A = 200 × 10⁻⁶ m²

Calculation:

σ = | = 9810 Pa

Result:

Stress Developed = 9.81 kPa

### 8. Speed Calculation of Robot

Formula:

Velocity = RPM × Circumference

Assume:

- Wheel Diameter = 70 mm
- Motor Speed = 100 RPM

Wheel Circumference:

C = πd = 3.14 × 0.07 = 0.2198 m

Linear Speed:

V = 100 × 0.2198 = 21.98 m/min

Convert:

V = = 0.366 m/s

Result:

Robot Speed ≈ 0.36 m/s

### 9. Efficiency Calculation

From report:

- Battery optimization improved efficiency by 20%

Formula:

Improved − Original
Efficiency Improvement = | × 100
Original

Assume:

- Original battery life = 26 min
- Improved = 31.2 min

Calculation:

× 100 = 20%

Result:

Efficiency Improvement = 20%

### 10. Wheel RPM Calculation

Formula:

60V
RPM =
πd

Given:

- Velocity = 0.366 m/s
- Diameter = 0.07 m

Calculation:

RPM = | = 99.8

Result:

Wheel RPM ≈ 100 RPM

### 11. Center of Gravity Calculation

Formula:

Σmx

xcg=
Σm
Assume:

Component Mass (kg) Distance (m)

Battery | 0.12 | 0.1
Arm | 0.30 | 0.25
Chassis | 0.50 | 0.15

Calculation:

xcg=

Result:

xcg= 0.176 m

### 12. Load Distribution Calculation

Formula:

Total Weigℎt
Load per wℎeel =
Number of Wℎeels

Assume:

- Total Weight = 1.2 kg
- Wheels = 4

Calculation:

= 0.3 kg

Result:

Load per Wheel = 0.3 kg

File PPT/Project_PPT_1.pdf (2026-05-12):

Project Topic Approval Presentation (Stage-1) on

## Robotic Arm with wheel for cold storage environment

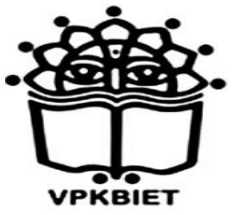
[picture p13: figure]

### Department of Mechanical Engineering

### Vidya Pratishthan’s Kamalnayan Bajaj Institute of Engineering and Technology, Baramati

2024-2025

## Presented By

BHOSALE SUBODH SHIRISH(244418) PATIL GIRISH ASHOK(244425) JADHAV UTKARSH SANTOSH(244426) PORE OMKAR ASHOK(244460)

## Project Guide

### Prof. S. H. Kumbhar

(Dept. of Mechanical Engg.)

1

# Introduction

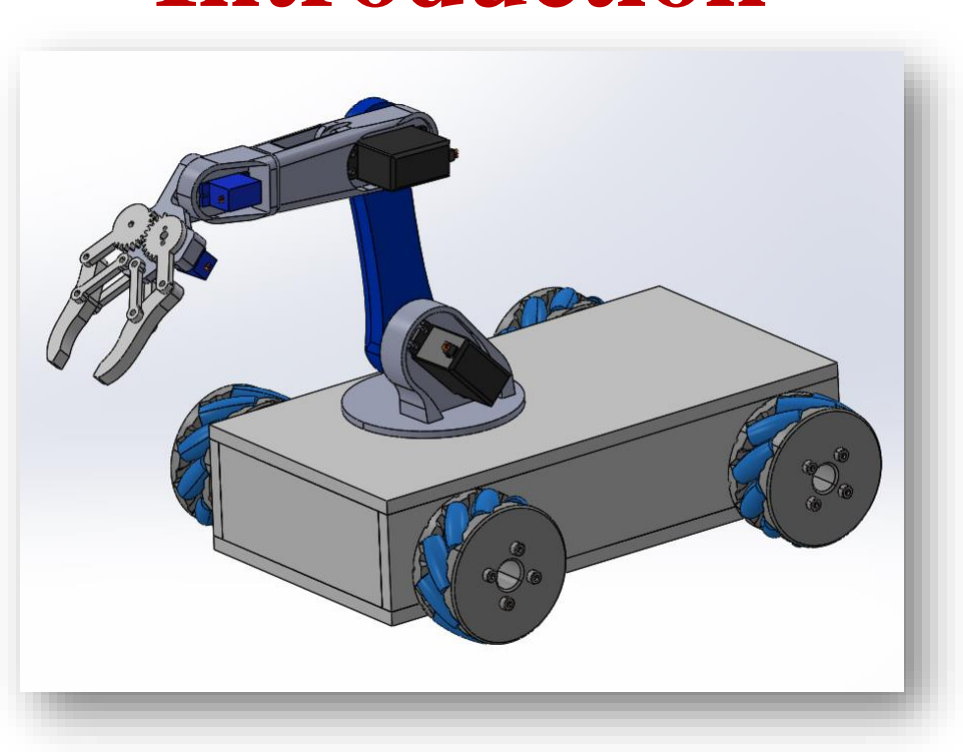
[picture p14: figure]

VPKBIET/BE-Mech. Sem-I/Project Topic Approval Presentation/27-07-24 | 2/14
- Our project focuses on developing a robotic arm with wheels for cold storage environments.
- This solution aims to make handling and moving items more efficient in cold storage.

# Problem Definition

VPKBIET/BE-Mech. Sem-I/Project Topic Approval Presentation/27-07-24

- Problem Description:
- cold storage environment need efficient systems for handling and moving items.
- Extreme temperatures make manual handling difficult.
- Significance and Impact:
- Manual labor in cold storage environment is challenging due to the harsh environment.
- Leads to reduced efficiency and increased risk of health issues for workers.
- Importance of Solving the Problem:
- Developing a robotic arm with wheels for cold storage environment can:
- Improve efficiency.
- Reduce labor costs.
- Enhance safety for workers.

3/14

# Literature survey

VPKBIET/BE-Mech. Sem-I/Project Topic Approval Presentation/27-07-24 | 4/14
- Key Findings:
Robotic arms are widely used in various industries for automation.

Research shows that automation improves efficiency and reduces human error.

- Relevant Studies and Technologies:
Studies on the use of robotic arms in manufacturing and logistics.

Technologies for robotic mobility and navigation.

- Gaps in Knowledge:
Limited focus on robotic arms specifically for cold storage environments.

Need for solutions that address extreme temperature conditions in cold storage environment

# State of Art

VPKBIET/BE-Mech. Sem-I/Project Topic Approval Presentation/27-07-24

## While traditional methods are limited by temperature and adaptability, current innovations aim to enhance efficiency with advanced materials and AI-driven navigation, addressing the unique challenges of cold

storage environment.

5/14

# Objectives

VPKBIET/BE-Mech. Sem-I/Project Topic Approval Presentation/27-07-24

- Design and Develop: Create a robotic arm with wheels specifically for cold storage environments.
- Enhance Efficiency: Improve item handling and movement in cold storage.
- Ensure Safety: Reduce manual labor and enhance worker safety in cold environments.
- Evaluate Performance: Test and measure the efficiency and effectiveness of the robotic arm in real-world conditions.

6/9

# Methodology

VPKBIET/BE-Mech. Sem-I/Project Topic Approval Presentation/27-07-24 | 7/14
- Research & Planning:
Conduct a literature review on existing technologies. Define project specifications and requirements.
- Design & Development:
Develop design prototypes for the robotic arm and mobility system. Use CAD tools for detailed design.
- Testing & Evaluation:
Build and test prototypes in simulated cold storage environments. Analyze performance and make necessary adjustments.
- Implementation & Analysis:
Finalize design and integrate system components. Evaluate the system’s effectiveness and compile results.

# Significance of the Project

VPKBIET/BE-Mech. Sem-I/Project Topic Approval Presentation/27-07-24 | 8/14
- Applications:

Automated handling of goods in cold storage facilities. Improved efficiency in warehouse and logistics operations.

- Significance:

Reduces labor costs and enhances safety in cold storage environments. Contributes to advancements in automation technology and robotics.

- Benefits:

Increased operational efficiency.
Enhanced worker safety and reduced manual labor

# Plan of Work

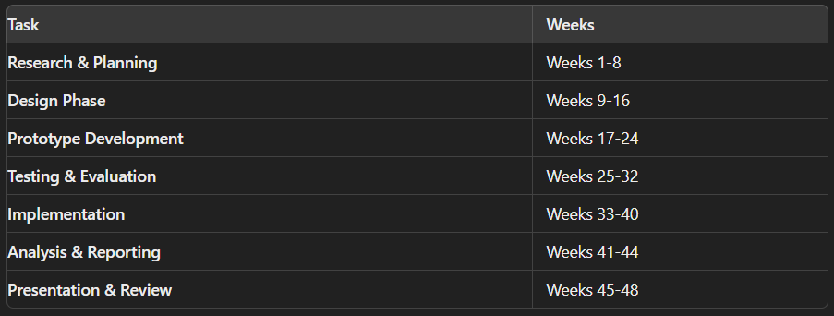
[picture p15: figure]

VPKBIET/BE-Mech. Sem-I/Project Topic Approval Presentation/27-07-24 | 9/14

# References

VPKBIET/BE-Mech. Sem-I/Project Topic Approval Presentation/27-07-24

1) Smith, J. A., & Doe, R. (2022). Robotic Arms in Industrial Automation. Journal of Robotics, 15(4), 123-134. https://doi.org/10.1234/jrobotics.2022.5678
2) Lee, C., & Wang, H. (2021). Advancements in Cold Storage Automation. International Conference on Robotics and Automation, 98-106.

10/14

# THANK YOU

VPKBIET/BE-Mech. Sem-I/Project Topic Approval Presentation/27-07-24 | 11/14

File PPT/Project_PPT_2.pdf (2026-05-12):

Project Progress Presentation-I on

# Automated Mobile Robotic Arm for Cold Storage Operations

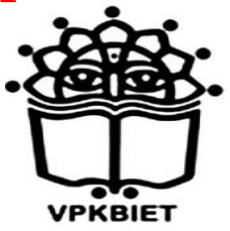
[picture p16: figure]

### Department of Mechanical Engineering

### Vidya Pratishthan’s Kamalnayan Bajaj Institute of Engineering and Technology, Baramati

2024-2025

## Presented By

BHOSALE SUBODH SHIRISH(244418) PATIL GIRISH ASHOK(244425) JADHAV UTKARSH SANTOSH(244426) PORE OMKAR ASHOK(244460)

## Project Guide

### Prof. S. H. Kumbhar

(Dept. of Mechanical Engg.)

1

# Updated Literature Review

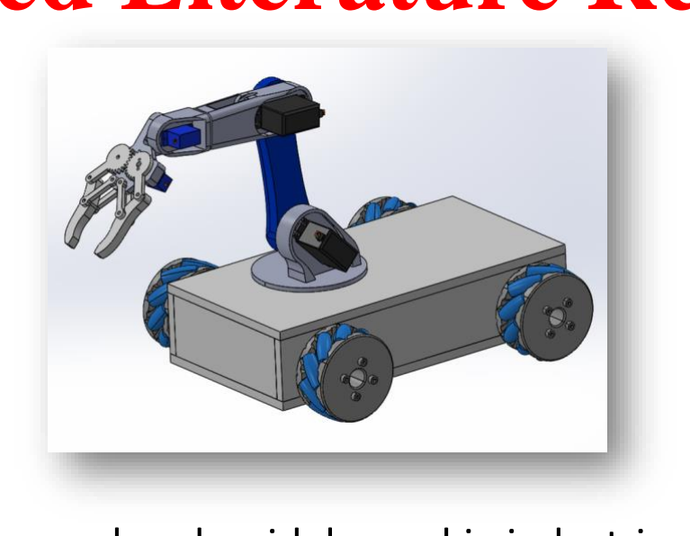
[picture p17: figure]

VPKBIET/BE-Mech. Sem-I/Project Topic Approval Presentation/27-07-24 | 2/14

Relevant Technologies:
•Robotics and automation are already widely used in industries like logistics and cold storage. However, most of these systems are either stationary or have limited mobility. Technologies like automated conveyor belts, robotic forklifts, and stationary robotic arms are commonly used to improve efficiency in cold environments.

Gaps in Knowledge:
•Although many studies focus on robots working in challenging environments, there is limited research on mobile robotic systems specifically designed to operate in cold storage. Most robotic systems are not built to handle the combination of mobility, precision, and durability required in such low-temperature environments.

# Suggestions from Previous Presentation

VPKBIET/BE-Mech. Sem-I/Project Topic Approval Presentation/27-07-24 | 3/14

•Suggestion 1: Change title to better reflect the project's scope.

### Compliance: Updated the title to “Automated Mobile Robotic Arm for Cold Storage Operations.”

### •Suggestion 2: Consider how the robotic arm will sustain operation in a cold

storage environment.

### Compliance: Selected the MG996R servo motor (operating range -10°C to +60°C) and Samsung Cell Premium Li-Ion 7.4V 2600mAh battery (operating

range -20°C to +60°C).

# Progress – Servo Motor Selection

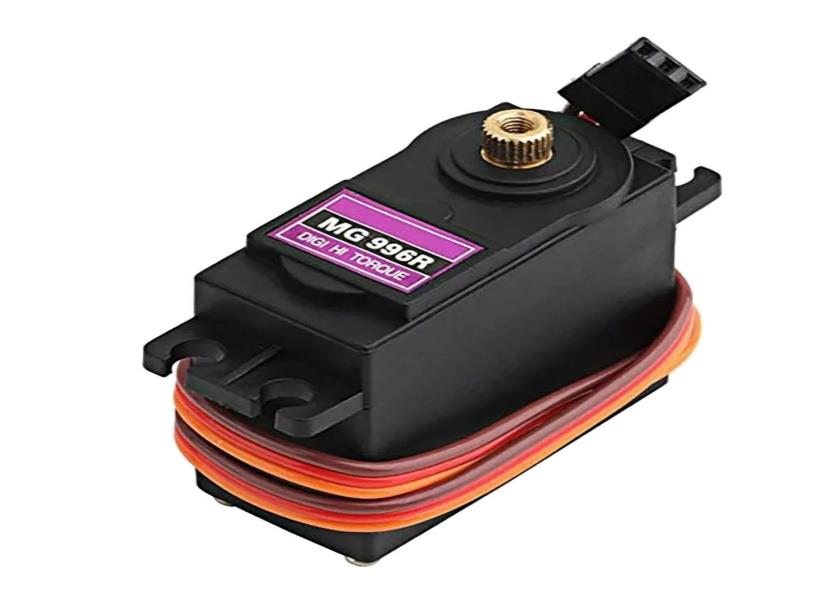
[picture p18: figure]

VPKBIET/BE-Mech. Sem-I/Project Topic Approval Presentation/27-07-24 | 4/14

•Final Selection: we selected the MG996R servo motor, which is capable of functioning within a temperature range of -10°C to +60°C, making it suitable for cold storage conditions.
•Performance: The MG996R motor is known for providing sufficient torque and precision, which is crucial for the accurate movement of the robotic arm. It has a maximum torque of 11 kg/cm, ensuring the arm can handle moderate loads with high accuracy, even in low-temperature environments.

# Progress – Battery Selection

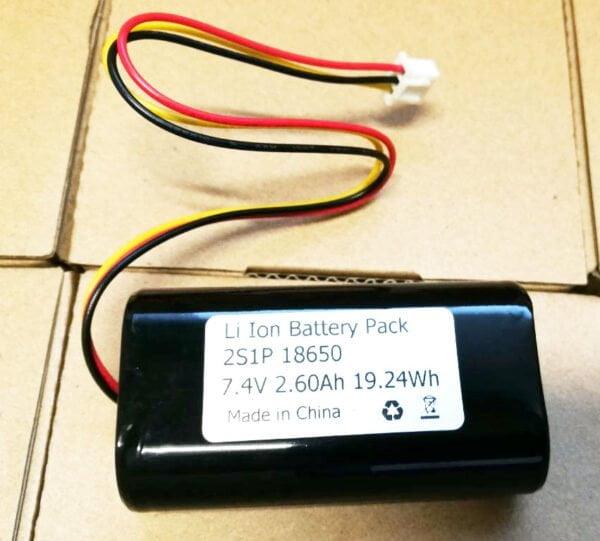
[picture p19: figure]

VPKBIET/BE-Mech. Sem-I/Project Topic Approval Presentation/27-07-24 | 5/14

•After evaluating various battery options, we selected the Samsung Cell Premium Li-Ion 7.4V 2600mAh, suitable for cold environments (-20°C to 60°C).
•Ensures prolonged operation of the robotic arm in cold conditions.

# Progress – Servo Controller

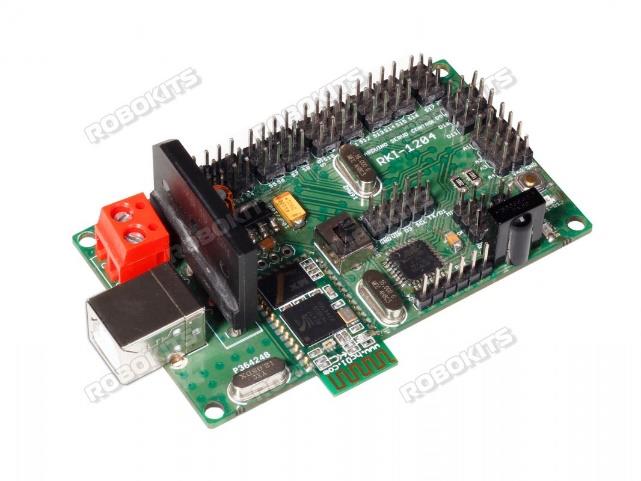
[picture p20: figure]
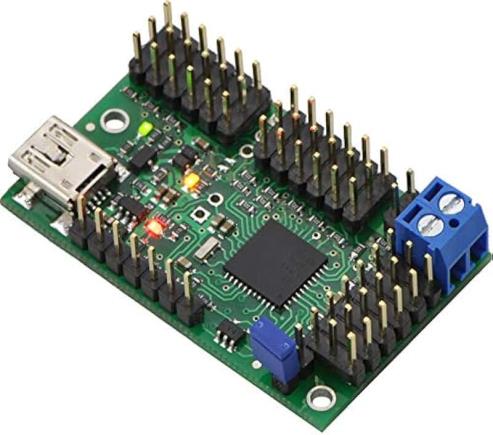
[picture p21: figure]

VPKBIET/BE-Mech. Sem-I/Project Topic Approval Presentation/27-07-24 | 6/9

•Previous Challenges: In earlier projects, coding for precise and accurate movement of the robotic arm was challenging due to the complexity of managing motor positions with traditional methods.
•Solution Found: After extensive research, we found a servo controller that can control the MG996R servo motors through a PC or laptop using Bluetooth technology. This controller allows for real-time adjustments and more precise control of the robotic arm’s movements, simplifying the programming and ensuring smoother operation.

or

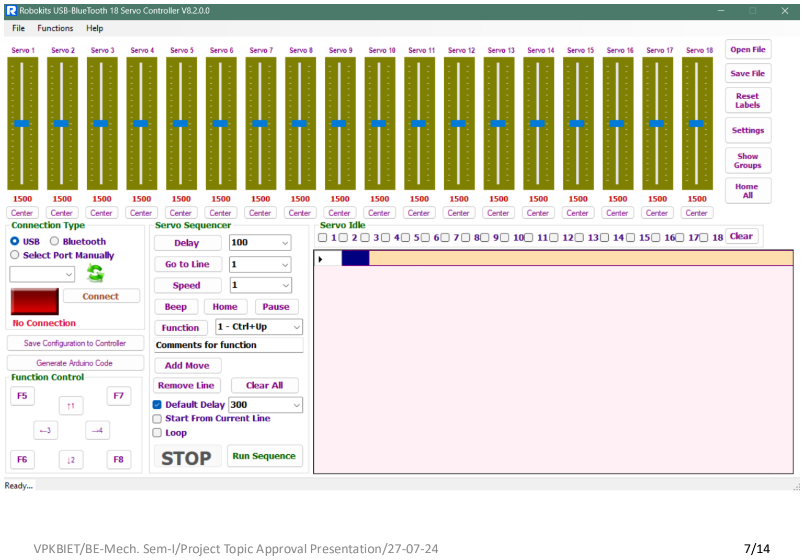
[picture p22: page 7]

VPKBIET/BE-Mech. Sem-I/Project Topic Approval Presentation/27-07-24 | 7/14

# Project cost

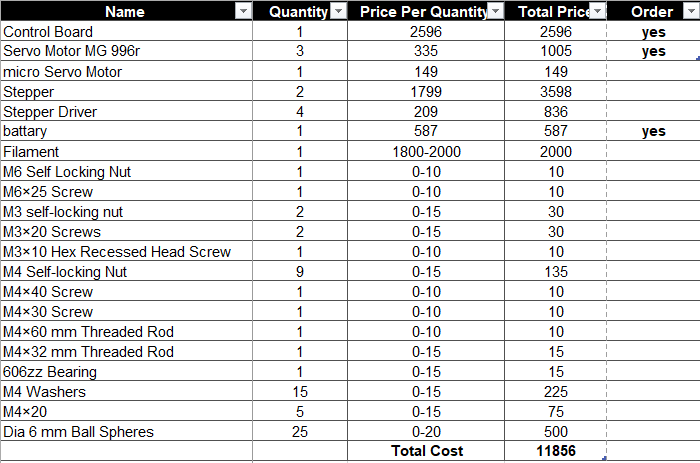
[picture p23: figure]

VPKBIET/BE-Mech. Sem-I/Project Topic Approval Presentation/27-07-24 | 8

# Cold Environment Simulation and Testing Plan

VPKBIET/BE-Mech. Sem-I/Project Topic Approval Presentation/27-07-24 | 9/14
- Next steps involve testing the system in a simulated cold storage environment.
- Planning to measure battery life, servo motor performance, and overall system stability at low temperatures.

# Future Work

VPKBIET/BE-Mech. Sem-I/Project Topic Approval Presentation/27-07-24 | 10/14
- Complete testing of the robotic arm in a cold storage environment.
- Fine-tune control systems and navigation.
- Explore further automation and AI integration for path planning.

# THANK YOU

VPKBIET/BE-Mech. Sem-I/Project Topic Approval Presentation/27-07-24 | 11/14

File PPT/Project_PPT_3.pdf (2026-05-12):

Project Progress Presentation-II on

## Automated Mobile Robotic Arm for Cold Storage Operations

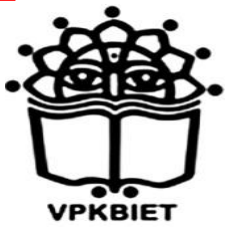
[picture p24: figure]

### Department of Mechanical Engineering

### Vidya Pratishthan’s Kamalnayan Bajaj Institute of Engineering and Technology, Baramati

2024-2025

## Presented By

BHOSALE SUBODH SHIRISH(244418) PATIL GIRISH ASHOK(244425) JADHAV UTKARSH SANTOSH(244426) PORE OMKAR ASHOK(244460)

## Project Guide

### Prof. S. H. Kumbhar

(Dept. of Mechanical Engg.)

1

## Suggestions from Previous Presentation

VPKBIET/BE-Mech. Sem-I/Project Topic Approval Presentation/27-07-24 | 2/14

•Suggestion: Show calculations for the components and the system.

•Compliance: We calculated torque, power consumption, battery capacity, and load capacity to ensure the proper functioning of the robotic arm in a cold storage environment.

# Progress – Components Acquired

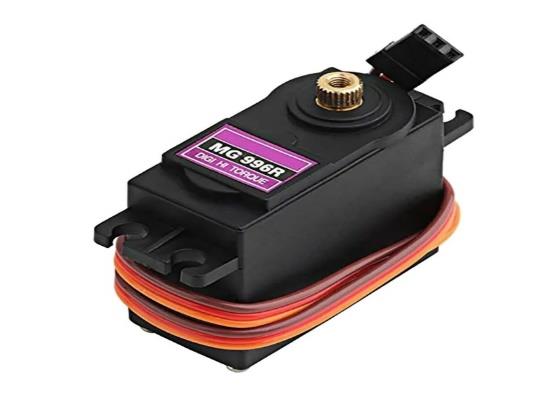
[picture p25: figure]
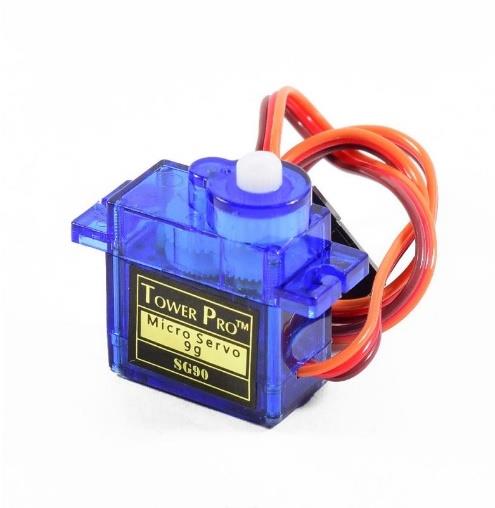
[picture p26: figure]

VPKBIET/BE-Mech. Sem-I/Project Topic Approval Presentation/27-07-24 | 3/14

•Purchased:
3 MG995 servo motors
Servo controller
Battery
Micro servo SG90
•All components have been connected.

# Progress – System Testing

VPKBIET/BE-Mech. Sem-I/Project Topic Approval Presentation/27-07-24 | 4/14

•Motor Setup: Successfully connected and tested three MG995 servo motors along with the SG90 micro servo.

•Control Method: Using the servo controller software, we ran tests to control the motors.

# Demonstration Video


VPKBIET/BE-Mech. Sem-I/Project Topic Approval Presentation/27-07-24 | 5/14

# Calculations


VPKBIET/BE-Mech. Sem-I/Project Topic
Approval Presentation/27-07-24 | 6

VPKBIET/BE

-Mech. Sem

I/Project Topic Approval
Presentation/27

-07

-24

7


VPKBIET/BE


-Mech. Sem

I/Project Topic Approval
Presentation/27

-07

-24

8


VPKBIET/BE

-Mech. Sem

-I/Project Topic
Approval Presentation/27

-07

-24

9

# Next Steps


VPKBIET/BE-Mech. Sem-I/Project Topic Approval Presentation/27-07-24 | 10/9

•3D Printing: Begin building and assembling 3D-printed parts for the robotic arm.

•Modification: Modify parts and assembly based on further testing and requirements.

# Conclusion

VPKBIET/BE-Mech. Sem-I/Project Topic Approval Presentation/27-07-24 | 11

•Our progress so far has built a solid base, making it easier to move forward with the next stages of development

•Moving forward with the building and testing phase to refine the arm’s performance in cold storage.

# THANK YOU

VPKBIET/BE-Mech. Sem-I/Project Topic Approval Presentation/27-07-24 | 12/14

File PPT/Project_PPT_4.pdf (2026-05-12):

### Progress Presentation-III

# Automated Mobile Robotic Arm for Cold Storage Operations


## Department of Mechanical Engineering

## Vidya Pratishthan’s Kamalnayan Bajaj Institute of Engineering and Technology, Baramati

2024-2025

## Presented By

BHOSALE SUBODH SHIRISH(244418) PATIL GIRISH ASHOK(244425) JADHAV UTKARSH SANTOSH(244426) PORE OMKAR ASHOK(244460)

## Project Guide

## Prof. S. H. Kumbhar

(Dept. of Mechanical Engg.)

# Literature review

2/14

Relevant Technologies:


•Robotics and automation are already widely used in industries like logistics and cold storage. However, most of these systems are either stationary or have limited mobility. Technologies like automated conveyor belts, robotic forklifts, and stationary robotic arms are commonly used to improve efficiency in cold environments.

Gaps in Knowledge:
•Although many studies focus on robots working in challenging environments, there is limited research on mobile robotic systems specifically designed to operate in cold storage. Most robotic systems are not built to handle the combination of mobility, precision, and durability required in such low-temperature environments.

# Project Setup


Components:
- Servo Motors
- Servo Controller
- Battery

-Stepper Motor

-DRV8825 Stepper Motor Driver Module (High Current)


-ControllersTech HC-05 master-slave 6pin Bluetooth Transceiver Module


# Progress of project work

- Accomplished Work:
- Bought and tested components like MG995 servo motors, a servo controller, a Samsung Li-Ion battery, and an SG90 micro servo.
- Successfully ran the motors using software and Bluetooth control.
- Planning to start 3D printing parts.


# Future Work


•3D printing the robotic arm

Next Steps
•Assembly Process
STEP 1 Put in position a 946 servo with the driving shaft forward
STEP 2 Fix the servo to the main base using the selftapping screws supplied with it
STEP 3 Insert 3 M3 nuts in the receptacles of the main base as swown.
STEP 4 Insert the 606 bearings in its housing and attach the plate to the main base using 3 M3 screws.
STEP 5 Verify the freedom of movement of the bearing.
STEP 6 Position the drive plate on the splined shaft and upper the driving printed gear.
Add one or two small selftapping screw to connect plate and the gear


STEP 7 Thera are two driving gears available one has 22 theet and the other 25 I made two because during printing of the base I've got some deformation and the two axis distance became smaller


STEP 8 Insert an M6 self locking nut in the receptacle of the swivel base then place in position le geared base and fix it using a couple of M3 screws and nuts as shown.


STEP 9 Fill the path using about 25 spheres with a diameter of 6mm.


STEP 10 Keeping the main base flat and the swivel element in contact with it, connect the two elements using an M6 screw.
STEP 11 Now the main base is finished. | STEP 12 Put in position the main arm and the vertical drive lever, connect them with the main base horizontal axis using a 4mm dia rod 33 mm long.



now mechanically assembled, ready to be driven by the electronics.


# Future Work

- Next Steps:
- - Integrate the arm with the mobile platform using Mecanum wheels.
- - Prepare the system for cold storage simulation and testing.
- - Test for battery life, motor performance, and stability in low temperatures.

# Conclusion

- Summarized Progress:
- - Components tested and running successfully.
- - 3D printing and assembly in progress.
- Next Steps:
- - Finalize assembly, integration, and testing in a cold storage environment.

# THANK YOU

14/14

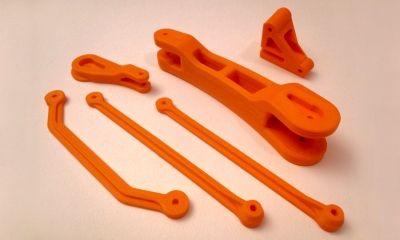
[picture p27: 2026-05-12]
Image/CAD_Designs/EBA2_0M2.jpg

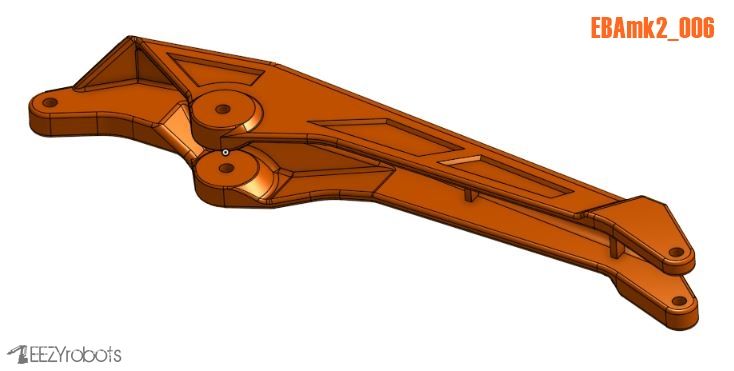
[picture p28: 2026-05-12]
Image/CAD_Designs/EBAmk2_006.JPG

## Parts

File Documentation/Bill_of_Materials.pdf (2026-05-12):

## Bill of Materials (BOM) – Non-Printed Parts

Sr.No. | Component Name | Specification / Description | Quantity
1 | Servo Motor | MG995 High Torque Servo | 3
2 | Micro Servo Motor | SG90 Micro Servo | 1
3 | Li-Ion Battery | Samsung 7.4V 2600mAh Battery | 2
4 | Servo Controller | USB Bluetooth 18 Servo Controller | 1
5 | Microcontroller Board | Arduino Uno | 2
6 | Wheels | Robotic Wheels | 4
7 | Motor Driver | L298N Motor Driver Module | 2
8 | Bluetooth Module | HC-05 Bluetooth Module | 2
9 | Stepper Motor | NEMA Stepper Motor | 4
10 | Bearings | 606ZZ and 608ZZ Bearings | 2
11 | 3D Printing Filament | PLA Filament | 2
12 | Jumper Wire | Male-Female Wire | 50
13 | Jumper Wire | Male-Male Wire | 50
14 | Jumper Wire | Female-Female Wire | 50
15 | Self-Locking Nut | M6 Nylon Lock Nut | 5
16 | Screw | M6 × 25 mm Screw | 5
17 | Self-Locking Nut | M3 Nylon Lock Nut | 5
18 | Screw | M3 × 20 mm Screw | 5
19 | Hex Recessed Head Screw | M3 × 10 mm | 5
20 | Self-Locking Nut | M4 Nylon Lock Nut | 10
21 | Screw | M4 × 40 mm Screw | 5
22 | Screw | M4 × 30 mm Screw | 5
23 | Threaded Rod | M4 × 60 mm Threaded Rod | 5
24 | Threaded Rod | M4 × 32 mm Threaded Rod | 5

Sr.No. | Component Name | Specification / Description | Quantity
25 | Washer | M4 Flat Washer | 20
26 | Screw | M4 × 20 mm Screw | 10
27 | Ball Spheres | Ø6 mm Steel Ball Spheres | 30

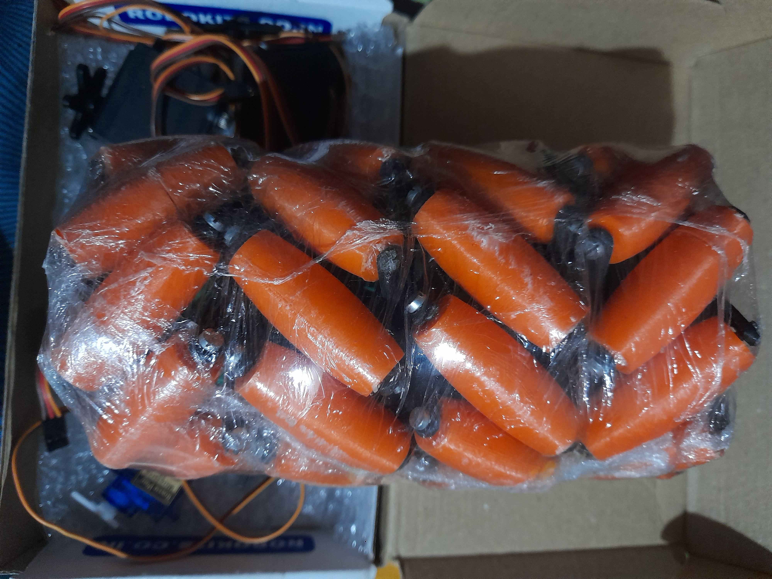
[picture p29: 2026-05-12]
Image/Components/Mccullum_Wheels.jpg

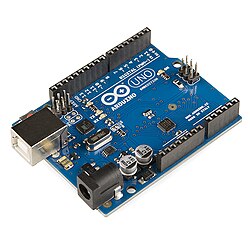
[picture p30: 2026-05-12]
Image/Components/Arduino_Uno.jpg

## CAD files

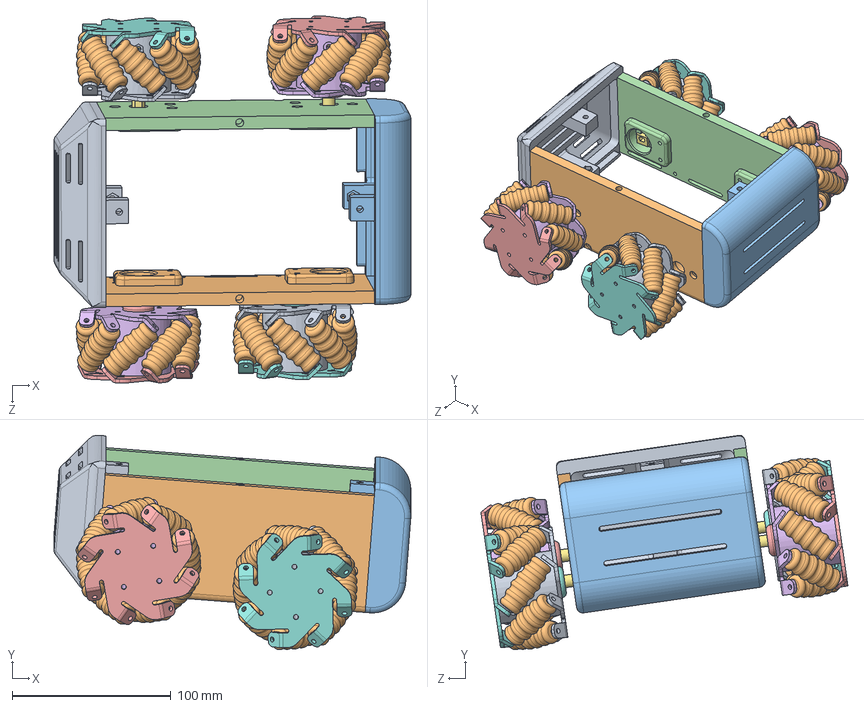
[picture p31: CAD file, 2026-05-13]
Assembly/Vehicle_Assembly.SLDASM
224.5 x 134.9 x 231.0 mm
Front
Left
Rear
Right
Wheel_Inner_RB_LF x 2
Wheel_Outer_RB_LF x 2
Wheel_Shaft x 4
Wheel_Inner_RF_LB x 2
Wheel_Outer_RF_LB x 2
Rollers x 32

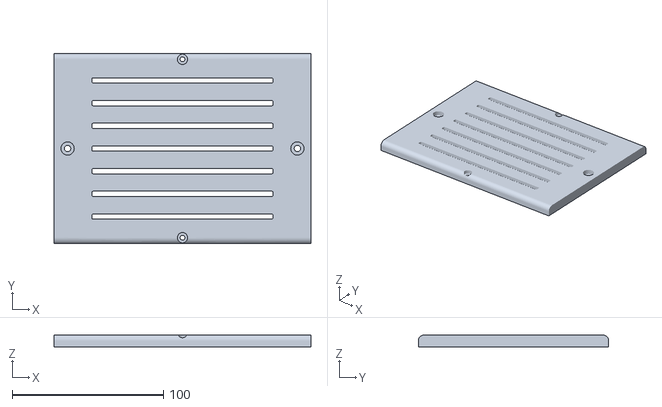
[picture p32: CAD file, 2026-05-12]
3D_Printing_Parts/STL_Files/STL_Vehicle/Assembly - Top-1.stl
170.0 x 126.0 x 8.00

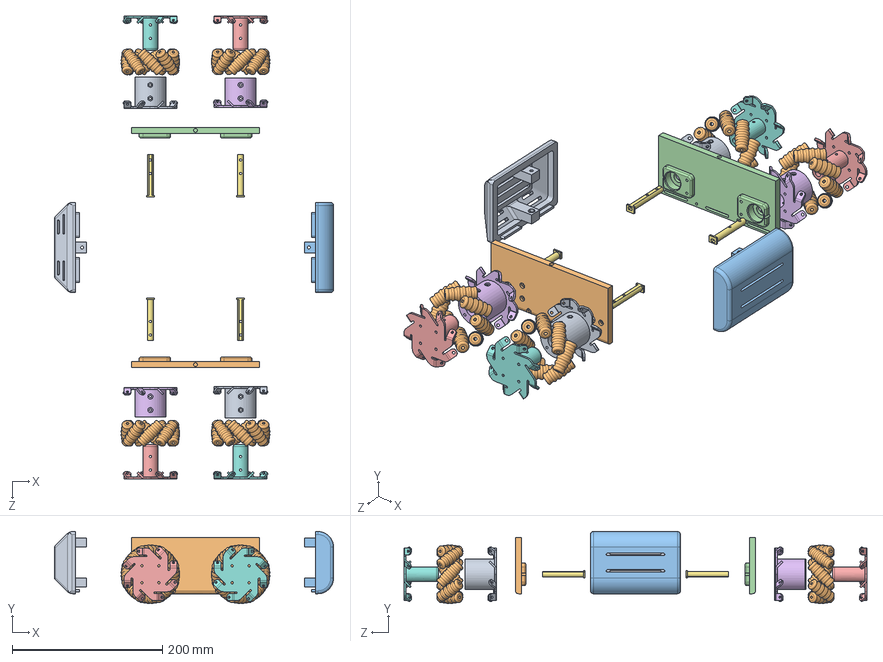
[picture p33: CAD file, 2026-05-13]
Assembly/Exp_Vehicle_Assembly.SLDASM
372.0 x 96.0 x 617.0 mm
Front
Left
Rear
Right
Wheel_Inner_RB_LF x 2
Wheel_Outer_RB_LF x 2
Wheel_Shaft x 4
Wheel_Inner_RF_LB x 2
Wheel_Outer_RF_LB x 2
Rollers x 32

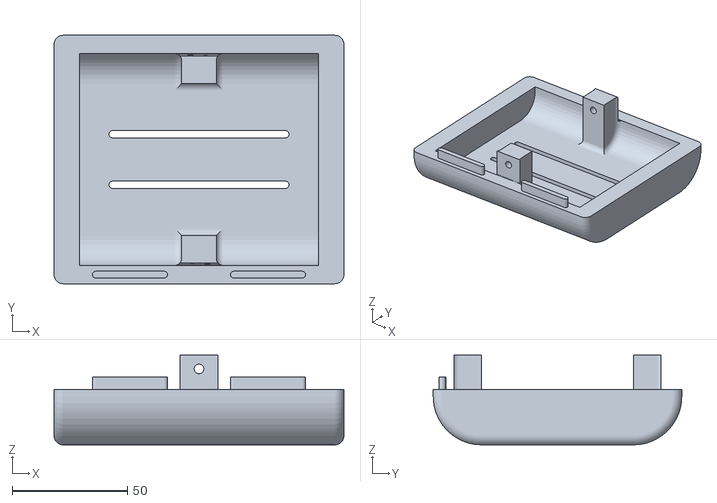
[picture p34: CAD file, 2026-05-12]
3D_Printing_Parts/STL_Files/STL_Vehicle/Assembly - Rear-1.stl
126.0 x 108.0 x 39.0

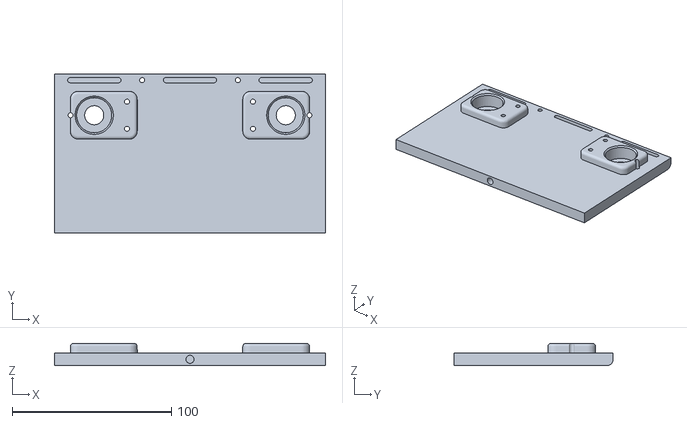
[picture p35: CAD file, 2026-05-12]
3D_Printing_Parts/STL_Files/STL_Vehicle/Assembly - Left-1.stl
170.0 x 100.0 x 14.0

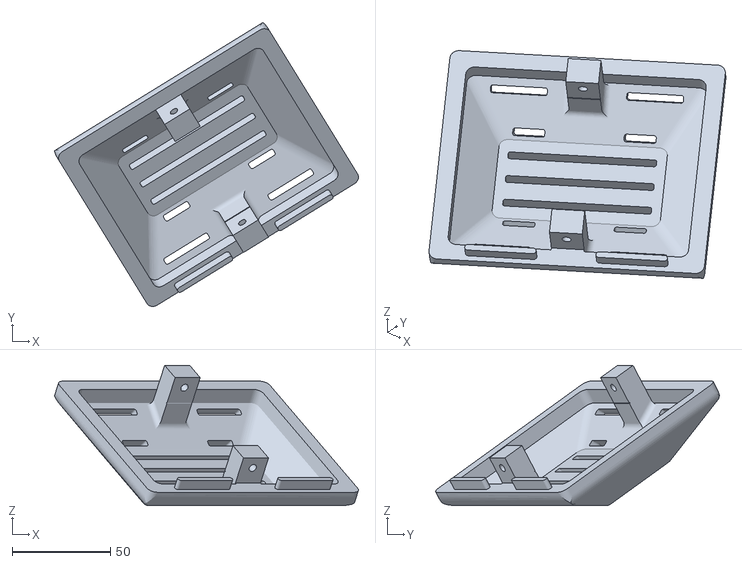
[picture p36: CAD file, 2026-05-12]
3D_Printing_Parts/STL_Files/STL_Vehicle/Assembly - Front-1.stl
154.9 x 144.7 x 71.5

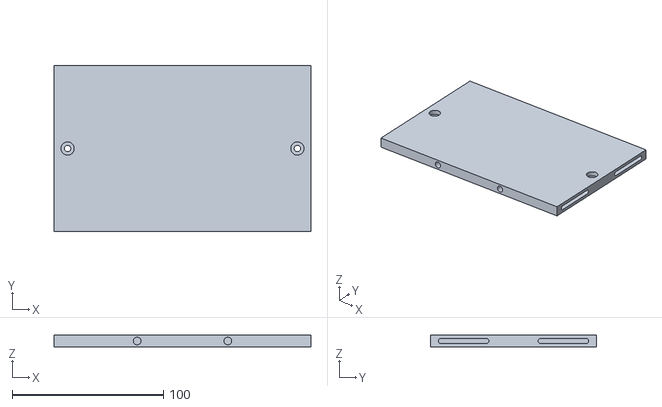
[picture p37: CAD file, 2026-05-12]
3D_Printing_Parts/STL_Files/STL_Vehicle/Assembly - Bottom-1.stl
170.0 x 110.0 x 8.00

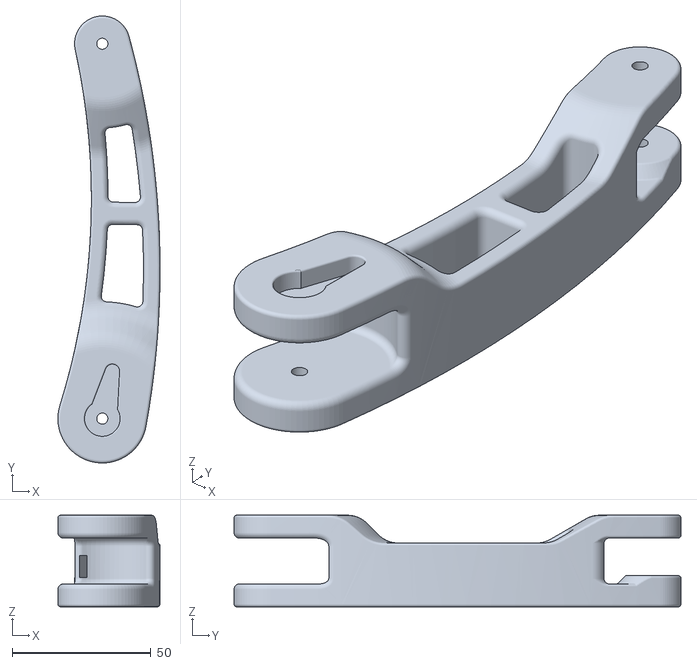
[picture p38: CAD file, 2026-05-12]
3D_Printing_Parts/STL_Files/STL_Robotic_Arm/EBAmk2_002_mainarm.STL
36.8 x 161.0 x 33.0

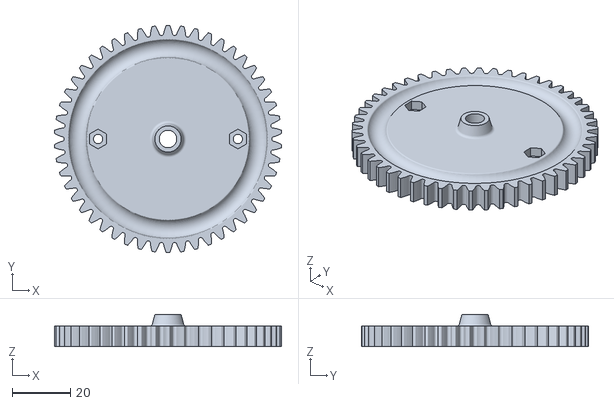
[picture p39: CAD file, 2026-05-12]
3D_Printing_Parts/STL_Files/STL_Robotic_Arm/EBAmk2_011_gearmast_full.STL
77.9 x 78.0 x 11.0

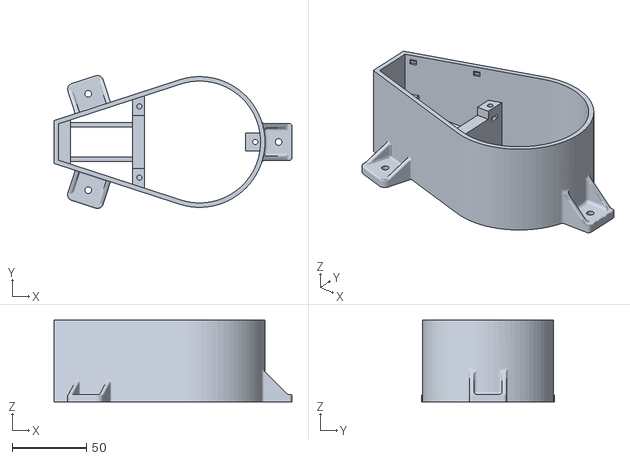
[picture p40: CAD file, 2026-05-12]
3D_Printing_Parts/STL_Files/STL_Robotic_Arm/EBAmk2_012_mainbase.STL
160.2 x 89.5 x 55.0

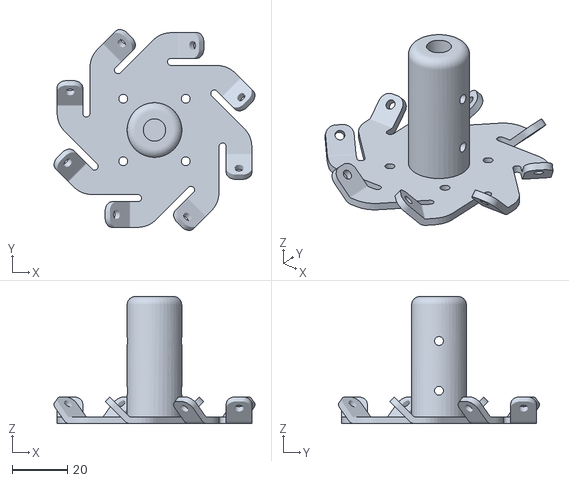
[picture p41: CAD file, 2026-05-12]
3D_Printing_Parts/STL_Files/STL_Maccullum_Wheel/Wheel_Inner_RB_LF.STL
72.7 x 72.7 x 46.0

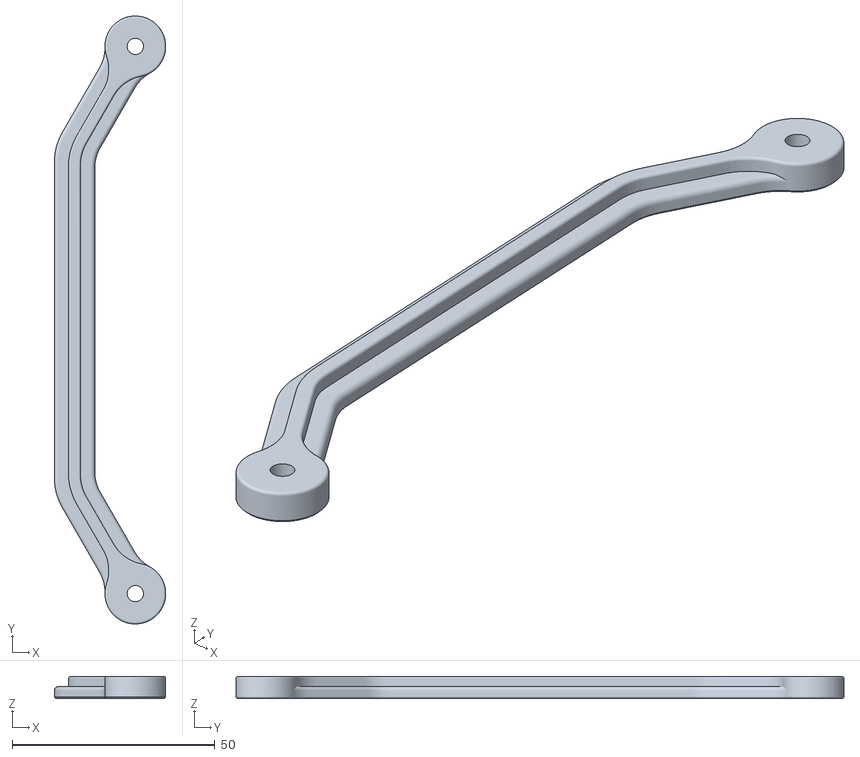
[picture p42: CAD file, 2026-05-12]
3D_Printing_Parts/STL_Files/STL_Robotic_Arm/EBAmk2_005_link135angled.STL
27.5 x 150.0 x 5.50

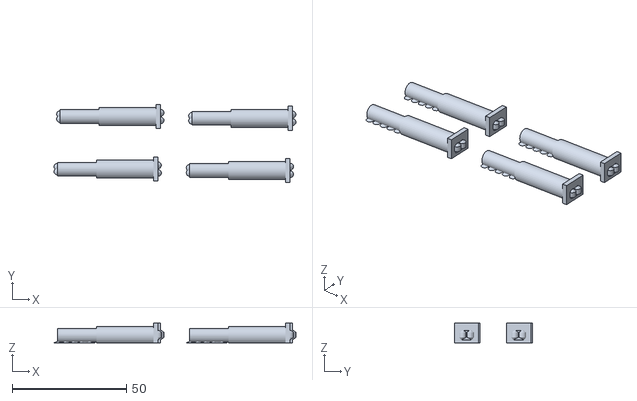
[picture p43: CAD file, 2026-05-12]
3D_Printing_Parts/STL_Files/STL_Vehicle/Wheel_Shaft 2.0[1].stl
105.9 x 34.2 x 8.60

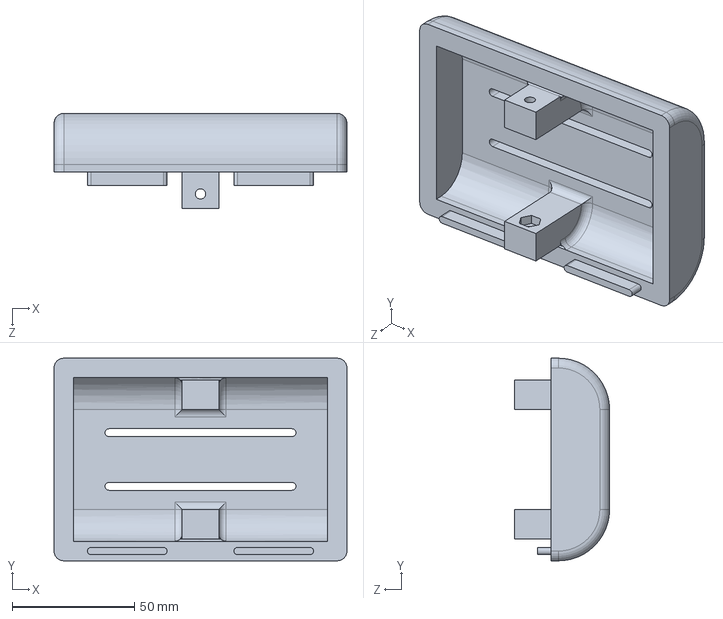
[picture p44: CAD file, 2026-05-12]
CAD_Designs/CAD_Design_Vehicle/Rear.SLDPRT
120.0 x 83.0 x 39.0 mm

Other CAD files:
3D_Printing_Parts/STL_Files/STL_Vehicle/Assembly - Right-1.stl
3D_Printing_Parts/STL_Files/STL_Maccullum_Wheel/Rollers.STL
3D_Printing_Parts/STL_Files/STL_Robotic_Arm/EBAmk2_006_horarm__.STL
CAD_Designs/CAD_Design_Vehicle/Left.SLDPRT
3D_Printing_Parts/STL_Files/STL_Maccullum_Wheel/Wheel_Outer_RF_LB.STL
3D_Printing_Parts/STL_Files/STL_Maccullum_Wheel/Wheel_Shaft.STL
3D_Printing_Parts/STL_Files/STL_Robotic_Arm/EBAmk2_001_base.STL
3D_Printing_Parts/STL_Files/STL_Robotic_Arm/EBAmk2_003_varm.STL
3D_Printing_Parts/STL_Files/STL_Robotic_Arm/EBAmk2_004_link135.STL
3D_Printing_Parts/STL_Files/STL_Robotic_Arm/EBAmk2_006_horarm_plate.STL
3D_Printing_Parts/STL_Files/STL_Robotic_Arm/EBAmk2_007_trialink.STL
3D_Printing_Parts/STL_Files/STL_Robotic_Arm/EBAmk2_008_link147_new.STL
3D_Printing_Parts/STL_Files/STL_Robotic_Arm/EBAmk2_009_trialinkfront.STL
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

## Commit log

2026-05-12 Design_And_Development_Of_Automated_Mobile_Robotic_Arm_Vehicle_For_Cold_Storage_Operations_Project uploaded
    [Assembly - Bottom-1.stl, Assembly - Front-1.stl, Assembly - Left-1.stl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]
2026-05-13 Create Arduino_Code
